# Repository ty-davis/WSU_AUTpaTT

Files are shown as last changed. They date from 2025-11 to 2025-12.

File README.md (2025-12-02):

# WSU_AUTpaTT

This repository contains all the files necessary to
build and operate the WSU_AUTpaTTv3, a device which
is used to characterize antennas in 3D. Lead by students
at Weber State University, WSU_AUTpaTTv3 is a project
which promotes collaboration and helps students learning
about electromagnetic radiation.

## Usage

The documentation is provided in the `docs/WSU_AUTpaTTv3_docs.pdf`
and outlines the contruction and operation of the device.

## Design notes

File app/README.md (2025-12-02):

# WSU_AUTpaTT
SDR-based antenna pattern measurement python code

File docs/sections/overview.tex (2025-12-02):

\chapter{Overview}

AUTpaTT v3 (Antenna Under Test Pattern Tracking, Version 3) is a low-cost, open-source 3-axis antenna pattern measurement system designed for education, research, and outreach.

This document is intended for a new user who receives the project files (for example via GitHub), purchases the required hardware, assembles the mechanical and electrical system, loads the firmware, runs the GUI, and successfully performs antenna measurements.

\section{System Goals}

\begin{itemize}
  \item Provide a low-cost, open-source antenna pattern measurement system.
  \item Use commercial off-the-shelf (COTS) and 3D-printed components where possible.
  \item Support three-axis motion (Azimuth, Elevation, Mast/Rotation).
  \item Integrate with software-defined radios (SDRs) for flexible RF measurements.
  \item Offer an easy-to-use GUI for control, data collection, and visualization.
\end{itemize}

\section{Assumed Background}

This guide assumes the user has basic familiarity with:

\begin{itemize}
  \item Microcontrollers and serial communication.
  \item 3D printing and/or mechanical assembly.
  \item Python environments and package installation.
\end{itemize}

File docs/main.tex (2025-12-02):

\documentclass[11pt,a4paper]{report}

\usepackage[margin=1in]{geometry}
\usepackage[T1]{fontenc}
\usepackage[utf8]{inputenc}
\usepackage{lmodern}
\usepackage{graphicx}
\usepackage{hyperref}
\usepackage{float}
\usepackage{booktabs}
\usepackage{siunitx}
\usepackage{listings}
\usepackage{xcolor}
\usepackage{svg}

\lstdefinestyle{mystyle}{
    backgroundcolor=\color{gray!5},   
    commentstyle=\color{green!60!black},
    keywordstyle=\color{blue},
    numberstyle=\tiny\color{gray},
    stringstyle=\color{orange},
    basicstyle=\ttfamily\small,
    breakatwhitespace=false,         
    breaklines=true,                 
    captionpos=b,                    
    keepspaces=true,                 
    % numbers=left,                    
    numbersep=5pt,                  
    showspaces=false,                
    showstringspaces=false,
    showtabs=false,                  
    tabsize=4,
    frame=single,
    rulecolor=\color{black!30},
    xleftmargin=10pt,
    framexleftmargin=10pt,
    framexrightmargin=5pt,
    framexbottommargin=5pt
}

\lstset{style=mystyle}

\hypersetup{
  colorlinks=true,
  linkcolor=blue,
  urlcolor=blue,
  citecolor=blue
}

\setlength{\parindent}{0pt}

\title{AUTpaTT v3\\\large Open-Source Antenna Pattern Measurement System\\Build and User Documentation}
\author{Weber State University\\Senior Capstone Project}
\date{\today}

\begin{document}

\maketitle
\tableofcontents
\clearpage

\include{sections/overview}               % 1
\include{sections/project_structure}      % 2
\include{sections/bom}                    % 3
\include{sections/mechanical_assembly}    % 4
\include{sections/electronics_wiring}     % 5
\include{sections/firmware}               % 6
\include{sections/gui}                    % 7
\include{sections/params}                 % 8
\include{sections/measurement_procedure}  % 9
\include{sections/troubleshooting}        % 10
\include{sections/acknowledgments}        % 11

\end{document}

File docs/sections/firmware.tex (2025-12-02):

\chapter{Firmware (STM32)}

\section{Firmware Contents}

The \texttt{/firmware/} directory should contain:

\begin{itemize}
  \item STM32CubeMX project configuration (if used).
  \item C source code and header files.
  \item A precompiled \texttt{.hex} or \texttt{.bin} file for quick flashing.
\end{itemize}

\section{Toolchain}

\begin{itemize}
  \item \textbf{STM32CubeProgrammer} for flashing firmware.
  \item Optional: \textbf{STM32CubeIDE} or other GCC-based toolchain for development.
\end{itemize}

\section{Flashing Procedure}

\begin{enumerate}
  \item Connect the STM32 Nucleo-L010RB board to the computer via USB.
  \item Open STM32CubeProgrammer and select the ST-LINK connection.
  \item Load the provided \texttt{.hex} file.
  \item Erase and program the device.
  \item Reset the board and verify that it enumerates as a serial port.
\end{enumerate}

\section{Serial Protocol} \label{sec:serial_protocol}

Describe here the basic serial commands used between the GUI and the firmware, for example:

\begin{itemize}
  \item Command to move to a given Azimuth/Elevation angle.
  \item Command to home each axis.
  \item Command to query current motor positions.
\end{itemize}

This documentation allows others to re-implement the controller if desired.

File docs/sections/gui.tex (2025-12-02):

\chapter{GUI Installation and Usage}

\section{Environment Setup}

The GUI is implemented in Python using PyQt6. A basic environment setup might be:

\begin{lstlisting}[language=bash]
python -m venv venv
source venv/bin/activate   # Windows: venv\Scripts\activate
pip install pyqt6 pyqt6-tools numpy matplotlib pyserial
# Add SDR-related packages as needed
\end{lstlisting}

\section{Launching the GUI}

From the \texttt{/gui/} directory:

\begin{lstlisting}[language=bash]
python main.py
\end{lstlisting}

\section{Main Features}

\begin{itemize}
  \item Connect/disconnect from the STM32 controller via serial port.
  \item Manual control of azimuth, and elevation.
  \item Display of current motor positions.
  \item Configuration of sweep ranges and resolution.
  \item Starting and stopping automated measurement runs.
  \item Visualization of 2D or 3D radiation patterns.
\end{itemize}

Include screenshots or GUI layout diagrams in the \texttt{/docs/} folder and reference them here.

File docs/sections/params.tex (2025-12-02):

\chapter{Configuration: \texttt{params.json}}

The file \texttt{params.json} contains configuration parameters used by both the firmware and GUI. Typical fields include:

\begin{itemize}
  \item Motor steps per revolution.
  \item Gear ratios for each axis.
  \item Default sweep ranges and step sizes.
  \item SDR sample rates and gains.
  \item Serial port settings (baud rate, timeouts, etc.).
\end{itemize}

\section{Editing Parameters}

Parameters may be edited in several ways:

\begin{itemize}
  \item Directly in a text editor (keeping valid JSON syntax).
  \item Through GUI controls that read and write this file.
\end{itemize}

Document here any parameters that are especially important for calibration and system performance.

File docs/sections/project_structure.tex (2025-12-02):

\chapter{Project Structure from GitHub}

After cloning the AUTpaTT v3 repository from GitHub, the expected directory structure is:

\begin{itemize}
  \item \textbf{/firmware/} -- STM32 Nucleo-L010RB source code, configuration files, and precompiled binaries.
  \item \textbf{/app/} -- Python app (using PyQt6) graphical user interface for system control and visualization.
  \item \textbf{/mechanical/} -- 3D models (STL, CAD), mechanical drawings, and assembly diagrams.
  \item \textbf{/electronics/} -- Schematics, wiring diagrams, and optional PCB design files.
  \item \textbf{/docs/} -- Additional documentation, figures, and exported PDFs.
  \item \textbf{/config/} or root file \texttt{params.json} -- System configuration parameters.
\end{itemize}

Each folder should include a minimal \texttt{README} that describes its content and how it is used.

You can add or update this structure as the project evolves.

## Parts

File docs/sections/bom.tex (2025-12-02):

\chapter{Bill of Materials (BOM)}

This chapter lists the components required to build AUTpaTT v3. Part numbers and vendors are examples; replace them with the exact parts you select.

\section{COTS items}

\begin{table}[H]
  \centering
  \makebox[\textwidth][c]{
      \begin{tabular}{@{}lll l@{}}
        \toprule
        Qty & Item & Part Number & Notes \\
        \midrule
        1 & STM32 Nucleo-L010RB dev board & NUCLEO-L010RB & Main controller \\
        2 & Stepper motor driver & TB6600 & One per axis \\
        1 & Power supply, 12~V & -- & \SIrange{3}{5}{A} recommended \\
        1 & USB-A to Mini-USB-B cable & -- & Recommend buying a 10ft cord \\
        -- & Assorted jumper wires & -- & Female--female and male--female \\
        2 & Stepper motor & NEMA17 & Azimuth, Elevation \\
        1 & Transmit Antenna & -- & Parabolic WIFI \\
        1 & Receive Antenna & -- & This is the AUT\\
        1 & Plastic Ball Bearing & McMaster-Carr, 6455K147 & --  \\
        1 & Plastic Ball Bearing & McMaster-Carr, 6455K54 & --\\
        1 & SMA Rotary Joint & FMRJ1002 & --\\
        2 & Timing Belt Pully & GT2-516-6mm & --\\
        1 & Timing Belt Pully & GT2-560-6mm & --\\
        2 & Hack RF Radios & -- & --\\
        - & SMA Cables & -- & Female to Female\\
        \bottomrule
      \end{tabular}
  }
  \caption{Core electronics components.}
\end{table}

\section{3D Printed Parts}

\begin{table}[H]
  \centering
  \begin{tabular}{@{}lll l@{}}
    \toprule
    Qty & Item & Example & Notes \\
    \midrule
    1 & v3\_mastYokeArmLeft & -- & --\\
    1 & v3\_mastYokeArmRight & -- & --\\
    1 & v3\_mastYokeBase & -- & --\\
    1 & v3\_mastYokeMotorMount & -- & --\\
    1 & v3\_AUT\_mountingPlate & -- & --\\
    1 & v3\_tube & -- & Can be made from plastic tube\\
    1 & v2\_mastBaseGear & -- & --\\
    1 & v2\_baseBearingFixture & -- & --\\
    1 & v2\_nemaMotorMount & -- & --\\
    \bottomrule
  \end{tabular}
  \caption{Printed Compoenents.}
\end{table}

\section{Mechanical Structure}

\begin{itemize}
  \item 3D-printed parts: all STL files in \texttt{/mechanical/} folder.
  \item Mechanical Assembly described in assembly drawing.
\end{itemize}

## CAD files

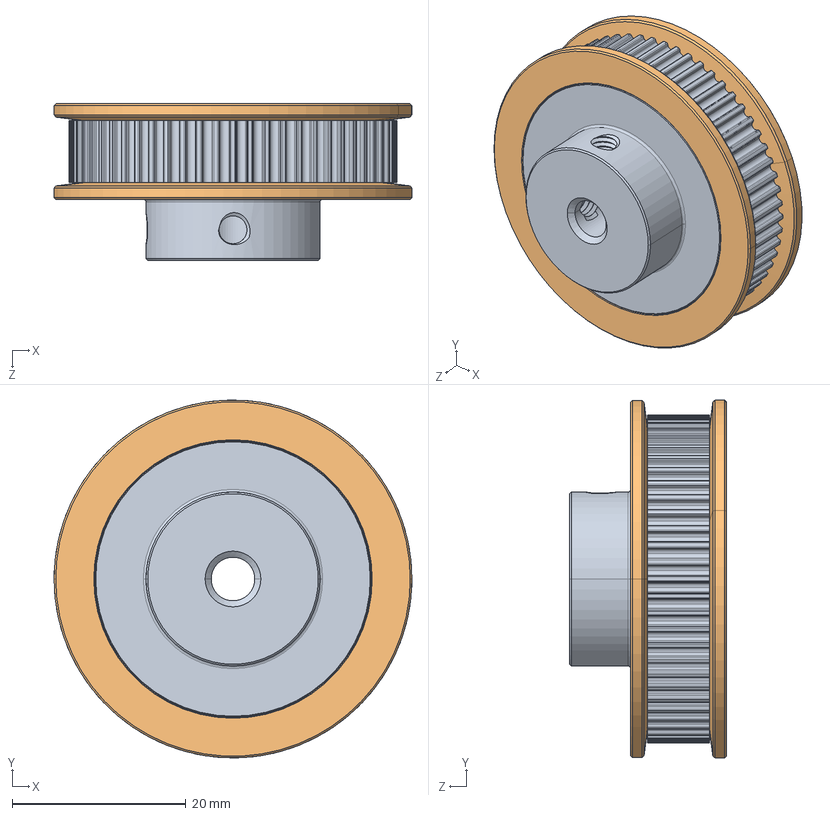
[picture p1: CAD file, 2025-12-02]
mechanical/solid models/60pitch pulley GT2 6mm ASSEMBLY.STEP
41.1 x 41.1 x 18.0 mm
Pulley part01 GT2 6mm
Gear 60pitch part02 x 2

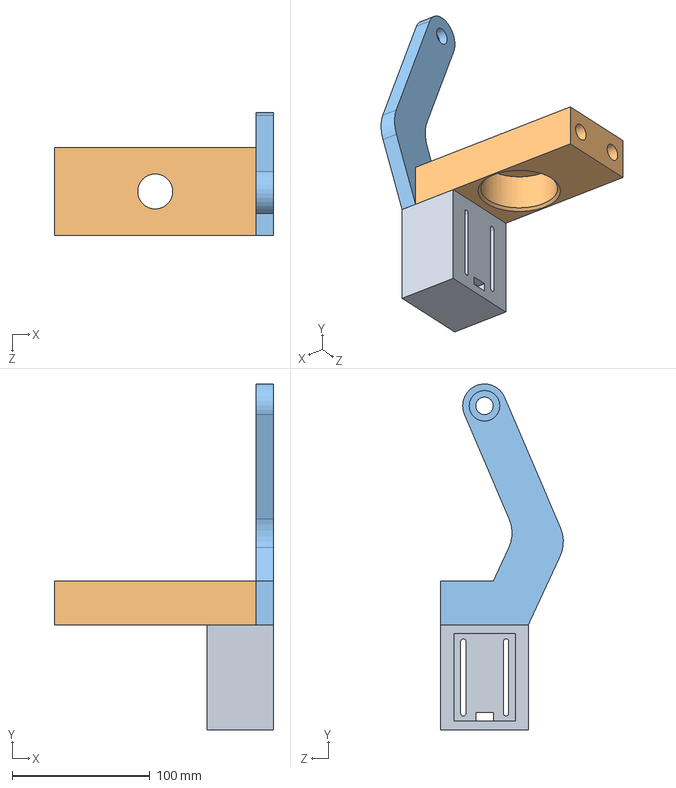
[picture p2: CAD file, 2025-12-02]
mechanical/solid models/v3_mastYoke.SLDASM
158.8 x 250.8 x 88.8 mm
v3_mastYokeArmLeft
v3_mastYokeBase
v3_mastYokeMotorMount

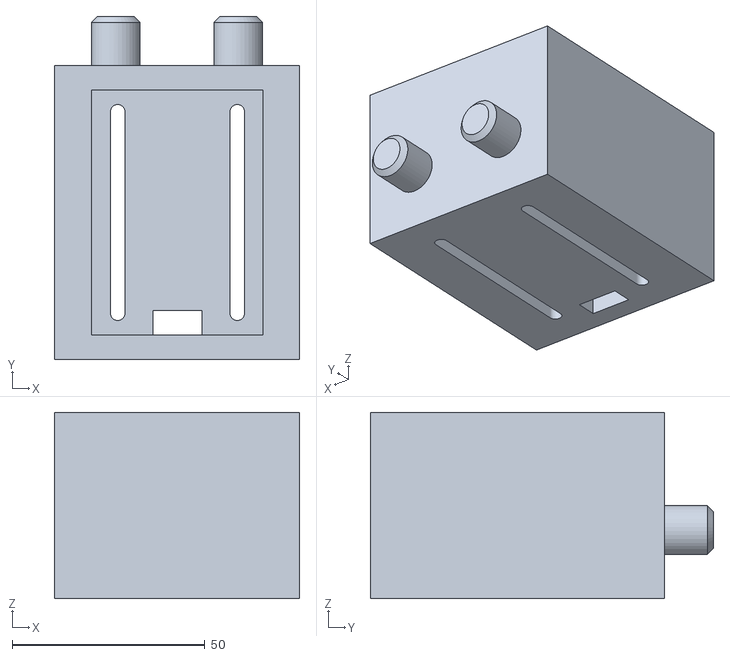
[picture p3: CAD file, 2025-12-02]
mechanical/stl exports (use me in slicer ide)/antenna support_v3_motor_mount.STL
63.5 x 88.9 x 48.3

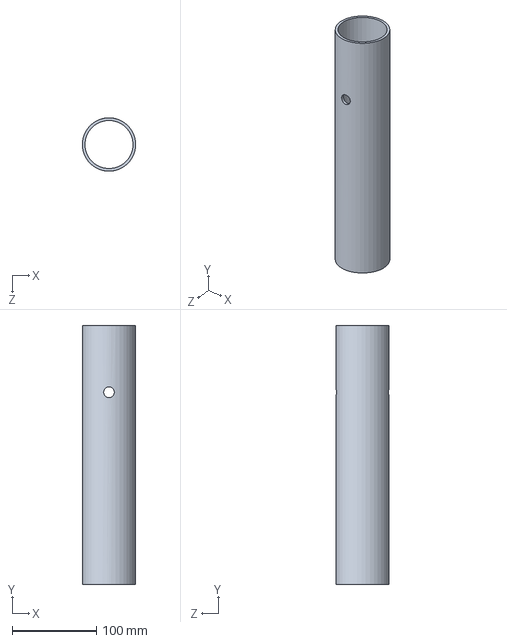
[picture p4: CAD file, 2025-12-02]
mechanical/solid models/v3_tube.SLDPRT
63.4 x 308.0 x 63.5 mm

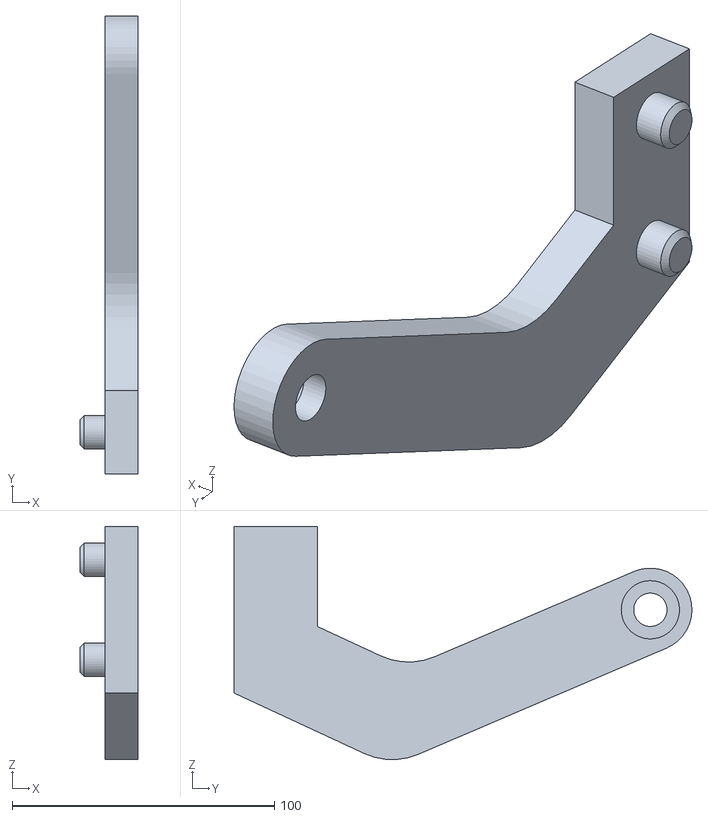
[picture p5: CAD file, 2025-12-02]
mechanical/stl exports (use me in slicer ide)/antenna support_v3_arm2.STL
22.2 x 174.6 x 88.8

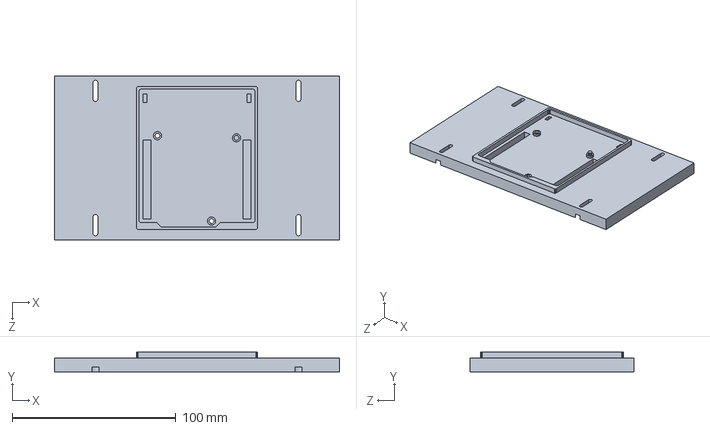
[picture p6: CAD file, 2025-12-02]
mechanical/solid models/STM_mount_plate.SLDPRT
174.0 x 12.0 x 100.0 mm

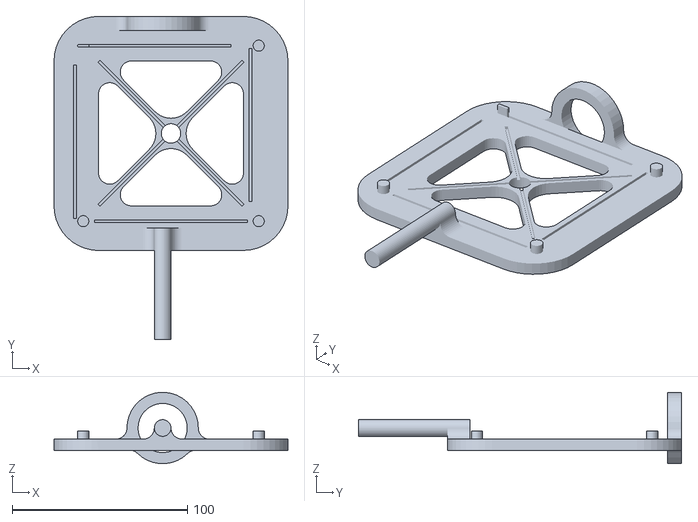
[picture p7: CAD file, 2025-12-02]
mechanical/stl exports (use me in slicer ide)/antenna mount_v3.STL
133.4 x 184.1 x 40.6

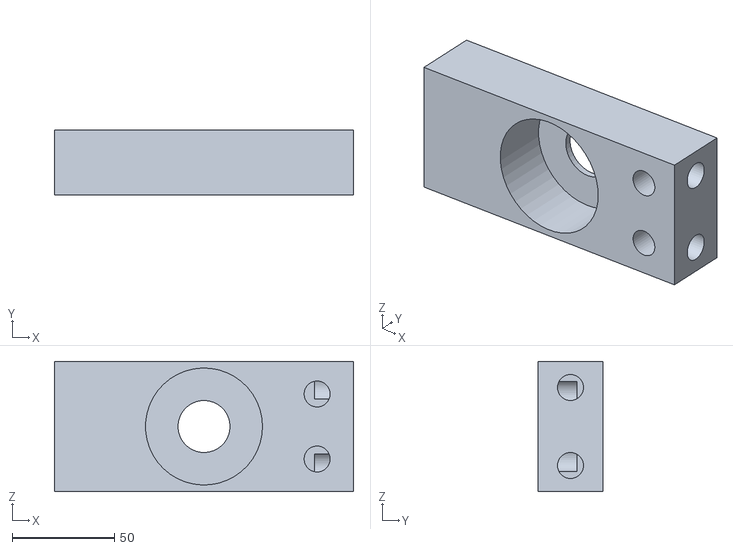
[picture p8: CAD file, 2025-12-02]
mechanical/stl exports (use me in slicer ide)/antenna support_v3_antenna base.STL
146.1 x 31.7 x 63.5

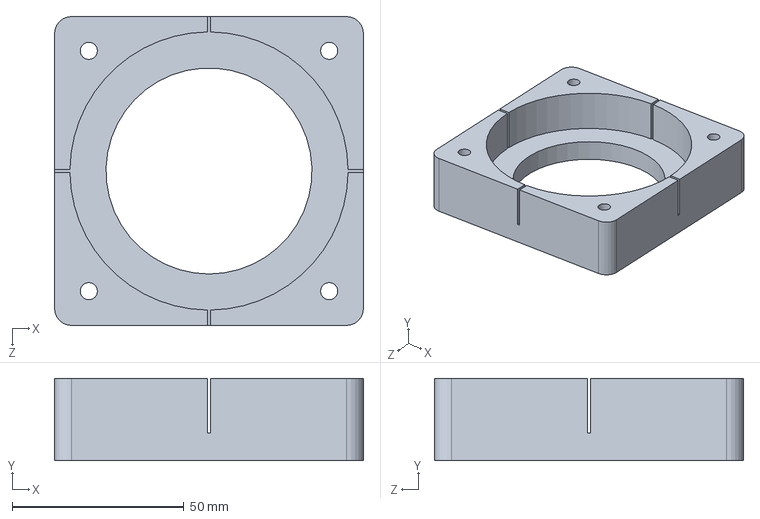
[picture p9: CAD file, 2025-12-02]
mechanical/solid models/v2_Base_BearingFixture.SLDPRT
90.0 x 24.0 x 90.0 mm

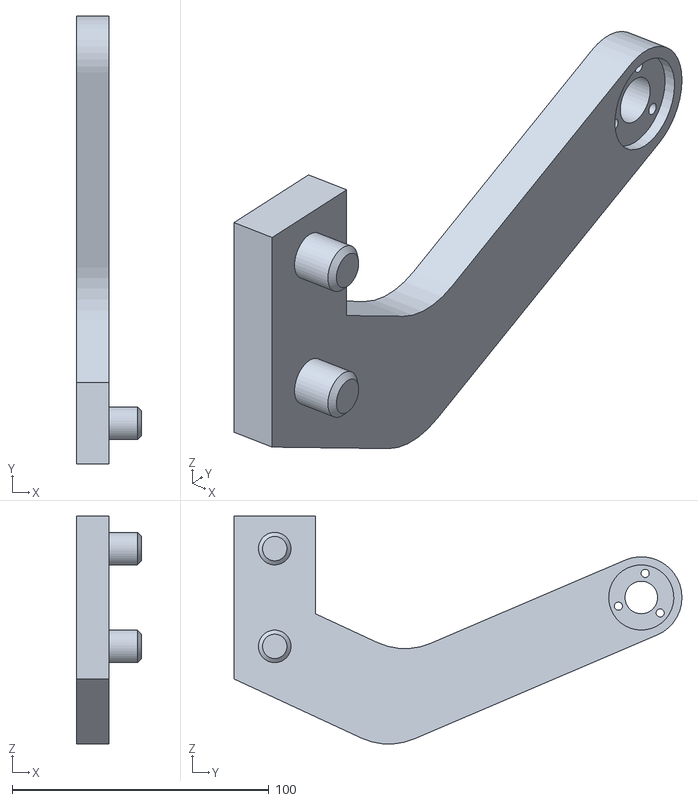
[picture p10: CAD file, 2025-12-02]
mechanical/stl exports (use me in slicer ide)/antenna support_v3_arm1.STL
25.4 x 174.6 x 88.8

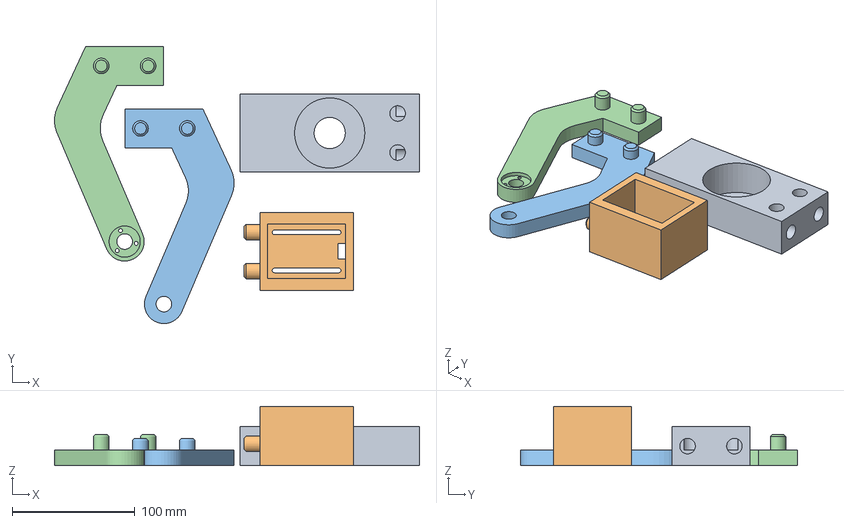
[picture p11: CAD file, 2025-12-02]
mechanical/stl exports (use me in slicer ide)/antenna support.3mf
296.9 x 225.5 x 48.3 mm
antenna support_v3_antenna base.STL
antenna support_v3_motor_mount.STL
antenna support_v3_arm2.STL
antenna support_v3_arm1.STL

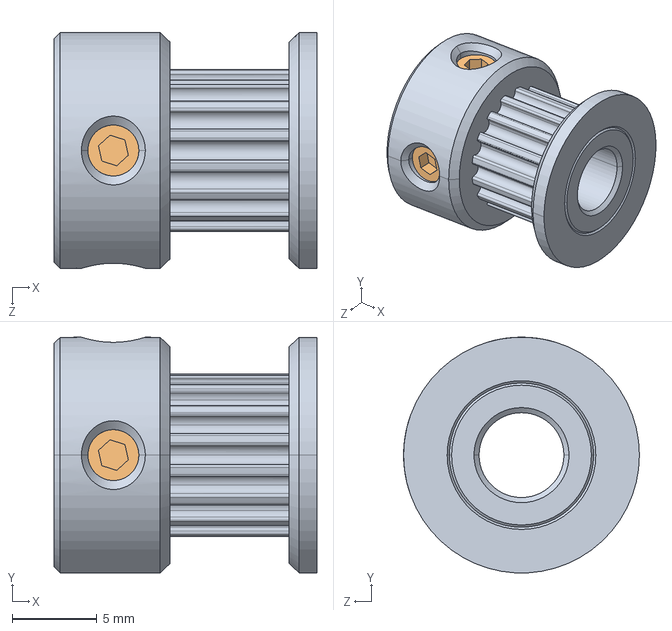
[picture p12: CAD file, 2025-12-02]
mechanical/solid models/GT2_16T.STEP
15.5 x 13.9 x 13.9 mm

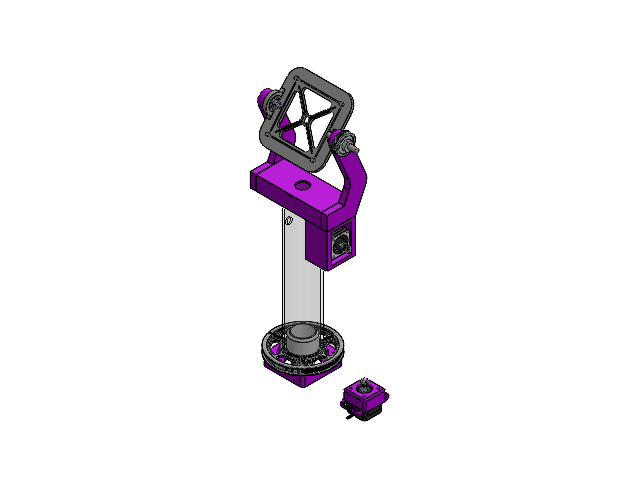
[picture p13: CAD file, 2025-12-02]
mechanical/solid models/v3AUTpaTT.SLDASM
v3_mastYokeArmLeft
v3_mastYokeArmRight
v3_mastYokeBase
v3_mastYokeMotorMount
v3_AUT_mountingPlate
6455K147_Plastic Ball Bearing
6455K54_Plastic Ball Bearing
FMRJ1002_3D.step
v3_tube
v2MastBase_Gear
v2_Base_BearingFixture
Nema17-17HS16-2004S1.step x 2
v2Nema_MotorMount
GT2_16T.step x 2
Pulley part01 GT2 6mm.STEP
Gear 60pitch part02.STEP x 2

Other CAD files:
mechanical/solid models/v3_mastYokeMotorMount.SLDPRT
mechanical/stl exports (use me in slicer ide)/STM_mount_plate.STL
mechanical/solid models/v3_mastYokeBase.SLDPRT
mechanical/solid models/Nucleo-64_Base.SLDPRT
mechanical/solid models/v3_mastYokeArmLeft.SLDPRT
mechanical/solid models/6455K147_Plastic Ball Bearing.SLDPRT
mechanical/solid models/6455K54_Plastic Ball Bearing.SLDPRT
mechanical/solid models/FMRJ1002_3D.step
mechanical/solid models/GT2_16T.SLDPRT
mechanical/solid models/Nema17-17HS16-2004S1.STEP
mechanical/solid models/v2MastBase_Gear.SLDPRT
mechanical/solid models/v2Nema_MotorMount.SLDPRT
mechanical/solid models/v3AUTpaTT.SLDDRW
mechanical/solid models/v3_AUT_mountingPlate.SLDPRT
mechanical/solid models/v3_mastYokeArmRight.SLDPRT

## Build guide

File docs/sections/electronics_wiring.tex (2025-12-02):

\chapter{Electronics and Wiring}

\section{Overview}

The electronics subsystem includes the STM32 Nucleo-L010RB board, stepper motor drivers, stepper motors, power supply, and connections to the SDRs and host computer.

\section{Wiring Guidelines}

Use the wiring diagram shown in Fig. \ref{fig:wiring} to connect the components of the system.
The pins on the STM32 are shown with two labels denoting the pin numbers of the STM32, and the pins
of the corresponding Arduino header that match and are shown on the board.

\begin{figure}[h!]
    \footnotesize
    \begin{centering}
    \includesvg[width=\textwidth]{figs/wiring}
    \end{centering}
    \caption{Wiring Diagram for STM32 and Motor Drivers.}
    \label{fig:wiring}
\end{figure}

A +12V power supply is required to power the motor drivers and is omitted here for brevity.

\section{Stepper Motor Drivers}

Each stepper driver (TB6600) connects to:
\begin{itemize}
  \item A Stepper Motor
  \item Power: +12~V and GND.
  \item Control signals from STM32: PUL, DIR, and ENABLE.
\end{itemize}

Unless another pulse/revolution ratio is desired and sent to the STM32 via the \hyperref[sec:serial_protocol]{serial protocol},
set the TB6600 motor drivers to 800 pulse/revolution.

\section{STM32 Nucleo Connections}

\begin{itemize}
  \item USB connection to the host computer for programming and serial communication.
  \item GPIO pins connected to each driver's PUL(-), DIR(-), and EN(-) pins.
  \item 5V pin connected to each driver's PUL(+), DIR(+), and EN(+) pins.
\end{itemize}

\section{SDR Connections}

\begin{itemize}
  \item The transmit SDR \& receiver SDR connects to the host computer via USB.
  \item The transmit SDR connects to WIFI band parabolic antenaa.
  \item The receive SDR connects to the AUT.
\end{itemize}

\begin{figure}[h!]
    \footnotesize
    \begin{centering}
    \includesvg[width=\textwidth]{figs/wiring_computer}
    \end{centering}
    \caption{Wiring Diagram for STM32 and Motor Drivers.}
    \label{fig:wiring}
\end{figure}

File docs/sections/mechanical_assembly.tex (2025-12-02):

\chapter{Mechanical Assembly}

This chapter describes the mechanical assembly of AUTpaTT v3. Detailed drawings and 3D models are provided in the \texttt{/mechanical/} directory of the repository.

\section{Printing and Preparing Parts}

\begin{enumerate}
  \item Print all STL files using suitable material (e.g., PLA, ABS, or PETG). The original project was printed using ABS plastic.
  \item Verify interference fit between bearings and housings, verify clearances, clean up any support material or rough edges.
\end{enumerate}

\section{Base Frame and Azimuth Axis}

\begin{enumerate}
  \item Assemble the following to the base plate per the assembly drawing.
    \begin{enumerate}

        \item v2\_nemaMotorMount w/ the azimuth stepper motor installed.
        \item v2\_baseBearingFixture
        \item GT2-516-6mm timing belt pully
    \end{enumerate}
  \item Assemble the mast bearing into the base bearing fixture and the v2\_mastBaseGear into the bearing. Verify interference fits for both items. Tape can be added to the parts to tighten the fit.
  \item Assemble the timing belt to the base gear and timing belt on the stepper motor then tighten the belt by sliding the motor mount in the slots and tighten down the motor mount bolts.
\end{enumerate}

\section{Elevation Axis}

\begin{enumerate}
  \item Mount the SMA Rotary joint to the v3\_mastYokeArmRight using fasteners.
  \item Assemble the larger plastic ball bearing (6455K147) into the v3\_AUT\_mounting plate.
  \item Assemble the other plastic ball bearing (6455K54) into the v3\_mastYokeArmLeft.
  \item Assemble the right and left arm to the mounting plate as shown in the assembly drawing and press the "dowels" on the arms into the v3\_mastYokeBase.
  \item Assemble the elevation stepper motor into the v3\_mastYokeMotorMount as shown in the assembly drawing. Do not fully tighten fasteners yet.
  \item Press the "dowels" of the motor mount into the yoke base with the rotor of the motor facing out per the assembly drawing.
  \item Assemble the GT2-516-6mm timing belt pully to the stepper motor and the GT2-560-6mm timing belt pully to the mounting plate. Note: the center bore of the GT2-560-6mm pully will need to be drilled out per the drawing to assemble correctly. 
  \item Assemble the timing belt to both pullies and tighten by sliding the stepper motor down in the mount and tightening the fasteners. 
  \item Press the tube into the mast yoke and then the tube to the base gear to finalize the mechanical assembly.
\end{enumerate}

\section{Finishing Assembly}

\begin{enumerate}
  \item Assemble the AUT to the mounting plate, a small flexible SMA cable will be needed to be assembled from the AUT to the rotary joint. 
  \item Assemble a longer SMA cable to the other side of the rotary joint and fish it through the side of the tube so it does not get tangled. This cable will go to the "receiving" SDR. 
  \item Assemble the motor drivers and micro controller to the v3\_STM\_mountingPlate.
  \item Wire the stepper motors and the independent power supply to the motor drivers and the motor drivers to the micro-controller per the wiring diagram. 
\end{enumerate}

\section{Mechanical Checks}

\begin{itemize}
  \item Ensure that all axes rotate freely with no binding.
  \item Check that cables and wires can be routed without snagging or wrapping around moving parts.
  \item Tighten all fasteners and recheck alignment.
\end{itemize}

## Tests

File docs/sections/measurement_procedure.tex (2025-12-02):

\chapter{Measurement Procedure}

This chapter describes a typical measurement workflow.

\section{Preparation}

\begin{enumerate}
  \item Verify all mechanical connections and ensure that all axes move freely.
  \item Power on the system and connect the STM32 and SDRs to the host computer.
  \item Launch the GUI and connect to the STM32 serial port.
\end{enumerate}

\section{Homing and Zeroing}

\begin{enumerate}
  \item Home each axis using the GUI (or manually move to a known reference position).
  \item Confirm that position readouts match expected zero positions.
\end{enumerate}

\section{Configuring a Sweep}

\begin{enumerate}
  \item Set the Azimuth start/stop angles and step size.
  \item Set the Elevation range (if used) and step size.
  \item Configure SDR parameters (center frequency, gain, sample rate).
\end{enumerate}

\section{Running a Measurement}

\begin{enumerate}
  \item Start the sweep from the GUI.
  \item Monitor progress and verify that the AUT moves as expected.
  \item Upon completion, save the measured data (e.g., CSV file).
\end{enumerate}

\section{Data Visualization}

\begin{itemize}
  \item Use built-in plotting in the GUI for quick inspection.
  \item Optionally, export data for use in external tools (MATLAB, Python scripts, etc.).
\end{itemize}

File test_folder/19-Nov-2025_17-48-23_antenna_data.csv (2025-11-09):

Experiment
% Mast Angle | Arm Angle | Background RSSI | Transmission RSSI

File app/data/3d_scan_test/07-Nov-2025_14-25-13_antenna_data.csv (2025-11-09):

Experiment
% Mast Angle | Arm Angle | Background RSSI | Transmission RSSI
-180 | -90 | 0.0 | 0.00411684038649162
-179 | -90 | 0.0 | 0.004273664321098818
-178 | -90 | 0.0 | 0.0044003070100847785
-177 | -90 | 0.0 | 0.00453865860839762
-176 | -90 | 0.0 | 0.004700895935805575
-175 | -90 | 0.0 | 0.004802841253129567
-174 | -90 | 0.0 | 0.004979065484833295
-173 | -90 | 0.0 | 0.005076450692446571
-172 | -90 | 0.0 | 0.005093597296887831
-171 | -90 | 0.0 | 0.00520148505978169
-170 | -90 | 0.0 | 0.005229538670096327
-169 | -90 | 0.0 | 0.005235615744217269
-168 | -90 | 0.0 | 0.005238796664103269
-167 | -90 | 0.0 | 0.00529496181347633
-166 | -90 | 0.0 | 0.005263079576342285
-165 | -90 | 0.0 | 0.0052378404977674676
-164 | -90 | 0.0 | 0.00522949492760347
-163 | -90 | 0.0 | 0.005087614010076423
-162 | -90 | 0.0 | 0.004946570425727888
-161 | -90 | 0.0 | 0.004802225764118687
-160 | -90 | 0.0 | 0.004718129664752715
-159 | -90 | 0.0 | 0.00448882863260915
-158 | -90 | 0.0 | 0.004361233526742504
-157 | -90 | 0.0 | 0.004182684319354149
-156 | -90 | 0.0 | 0.0040548761443367975
-155 | -90 | 0.0 | 0.0038261078965352944
-154 | -90 | 0.0 | 0.003637641713021363
-153 | -90 | 0.0 | 0.0034640284156706278
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

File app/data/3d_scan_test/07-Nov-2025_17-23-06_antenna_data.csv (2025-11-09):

Experiment
% Mast Angle | Arm Angle | Background RSSI | Transmission RSSI
-180 | -90 | 0.0 | 0.0035297520595307056
-179 | -90 | 0.0 | 0.003655941559245732
-178 | -90 | 0.0 | 0.0037861012826280486
-177 | -90 | 0.0 | 0.0038954217152386617
-176 | -90 | 0.0 | 0.0040336727183365485
-175 | -90 | 0.0 | 0.0041476016041917625
-174 | -90 | 0.0 | 0.004244900141386852
-173 | -90 | 0.0 | 0.00436989471997877
-172 | -90 | 0.0 | 0.004471388982411234
-171 | -90 | 0.0 | 0.004539627817103733
-170 | -90 | 0.0 | 0.0046478961513783095
-169 | -90 | 0.0 | 0.00468491141394872
-168 | -90 | 0.0 | 0.004732468586729701
-167 | -90 | 0.0 | 0.0047327627429095374
-166 | -90 | 0.0 | 0.004787630462647476
-165 | -90 | 0.0 | 0.004735022993450363
-164 | -90 | 0.0 | 0.004714587640699876
-163 | -90 | 0.0 | 0.004730252232252236
-162 | -90 | 0.0 | 0.004592589571733637
-161 | -90 | 0.0 | 0.004513919607516239
-160 | -90 | 0.0 | 0.004404593871840091
-159 | -90 | 0.0 | 0.0042957471446504894
-158 | -90 | 0.0 | 0.004204804774847104
-157 | -90 | 0.0 | 0.004077711335980914
-156 | -90 | 0.0 | 0.003960402165598614
-155 | -90 | 0.0 | 0.003793658109248999
-154 | -90 | 0.0 | 0.0036031659423111876
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

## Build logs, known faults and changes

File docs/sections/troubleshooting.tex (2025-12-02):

\chapter{Troubleshooting}

\section{Common Issues}

\subsection{Board Not Detected / USB Problems}

\begin{itemize}
  \item Check the USB cable; use a known good USB-A to Mini-USB-B cable.
  \item Some issues (e.g., ``USB LSD'' blinking) may indicate insufficient power or communication errors.
  \item Try a different USB port or powered hub.
\end{itemize}

\subsection{Stepper Motors Not Moving or Stalling}

\begin{itemize}
  \item Verify wiring from drivers to motors and from drivers to STM32.
  \item Check that the driver is receiving 12~V power.
  \item Adjust the current limit on the driver; too low can cause missed steps, too high can overheat.
\end{itemize}

\subsection{No SDR Signal}

\begin{itemize}
  \item Confirm that the correct SDR device index is selected in the GUI.
  \item Check frequency, gain, and antenna connections.
  \item Test the SDR separately with a simple spectrum viewer application.
\end{itemize}

\section{Debugging Tips}

\begin{itemize}
  \item Use serial terminal software to send simple commands to the STM32 and observe responses.
  \item Enable debug prints in the firmware and/or GUI.
  \item Test one axis at a time before running full 3D sweeps.
\end{itemize}

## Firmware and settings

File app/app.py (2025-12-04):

import sys
from PyQt6 import QtWidgets, uic
from PyQt6.QtGui import QShortcut, QKeySequence
from PyQt6.QtCore import QTimer
import plotting
import matplotlib.pyplot as plt
from params_manager import ParamsManager
import pprint
import time
import os
from motor_connection import MotorConnection
from serial.serialutil import SerialException
from scans import all_scans, AbstractScan
from datetime import datetime
import asyncio
import qasync


class MyMainWindow(QtWidgets.QMainWindow):
    def __init__(self, *args, **kwargs):
        super().__init__(*args, **kwargs)
        uic.loadUi("./gui/window.ui", self)

        self.setWindowTitle("WSU AUTpaTTv3")

        # Create timer
        self.timer = QTimer()
        self.timer.timeout.connect(self.poll_state)
        self.timer.start(100)   # update every 150 ms

        # load the parameters
        self.params_man = ParamsManager()

        self.mast_steps.setText(str(self.params_man.params['mast_steps']))
        self.mast_steps.editingFinished.connect(self.update_params)

        self.arm_steps.setText(str(self.params_man.params['arm_steps']))
        self.arm_steps.editingFinished.connect(self.update_params)

        self.logfile = None

        # configure the motor connection
        self.motor_conn = None
        # self.connect_to_stm32()
        self.update_motor_connection_state()

        # self.timer = QTimer()
        # self.timer.timeout.connect(self.poll_position)
        # self.timer.start(1000)

        # actions
        self.actionOpen_scan.triggered.connect(self.open_scan_file)
        self.actionMove_with_Arrow_Keys.triggered.connect(self.move_with_arrow_keys)
        self.actionEdit_Parameters.triggered.connect(self.edit_parameters)
        self.actionView_Parameters.triggered.connect(self.view_parameters)
        self.actionLoad_Parameters.triggered.connect(self.load_parameters)

        # buttons
        self.clear_plot_b.clicked.connect(self.clear_plot)
        self.move_with_arrows_button.clicked.connect(self.actionMove_with_Arrow_Keys.trigger)
        self.view_params_b.clicked.connect(self.actionView_Parameters.trigger)
        self.load_params_b.clicked.connect(self.load_parameters)

        self.start_button.clicked.connect(self.run_test)
        self.cancel_button.clicked.connect(self.cancel_test)
        self.moveAzimuthByButton.clicked.connect(lambda: self.motor_command('azm'))
        self.moveElevationByButton.clicked.connect(lambda: self.motor_command('elv'))
        self.moveAzimuthToButton.clicked.connect(lambda: self.motor_command('azm_to'))
        self.moveElevationToButton.clicked.connect(lambda: self.motor_command('elv_to'))
        self.calibrateButton.clicked.connect(lambda: self.motor_command('calibrate'))
        self.lockUnlockButton.clicked.connect(lambda: self.motor_command('toggle_lock'))

        self.connect_to_stm32_button.clicked.connect(self.connect_to_stm32)
        self.disconnect_from_stm32_button.clicked.connect(self.disconnect_from_stm32)

        self.cancel_button.hide()

        for scan in all_scans:
            self.select_scan.addItem(scan.name, scan)

    def update_params(self):
        try:
            self.params_man.params["mast_steps"] = int(self.mast_steps.text())
        except ValueError:
            self.mast_steps.setText(str(self.params_man.params["mast_steps"]))

        try:
            self.params_man.params["arm_steps"] = int(self.arm_steps.text())
        except ValueError:
            self.arm_steps.setText(str(self.params_man.params["arm_steps"]))

    @qasync.asyncSlot()
    async def poll_state(self):
        if not self.motor_conn or not self.motor_conn.serial_connection:
            return
        result = await self.motor_conn.send_command_async("GET_STATE")
        azm = int(result['azm']) / 8
        azm_degrees = azm * 10000 / self.params_man.params['azm_pulse_rev'] * 360 / self.params_man.params['azm_tooth_ratio']
        elv = int(result['elv']) / 8
        elv_degrees = elv * 10000 / self.params_man.params['elv_pulse_rev'] * 360 / self.params_man.params['elv_tooth_ratio']
        locked = bool(result['locked'])
        self.azimuthLocation.display(round(azm_degrees))
        self.elevationLocation.display(round(elv_degrees))
        if locked:
            self.lockUnlockButton.setText('Unlock Motors')
        else:
            self.lockUnlockButton.setText('Lock Motors')
        self.start_button.setEnabled(locked)
        self.moveAzimuthByButton.setEnabled(locked)
        self.moveElevationByButton.setEnabled(locked)
        self.moveAzimuthToButton.setEnabled(locked)
        self.moveElevationToButton.setEnabled(locked)
        self.calibrateButton.setEnabled(locked)
        self.move_with_arrows_button.setEnabled(locked)

    def edit_parameters(self):
        ...

    @qasync.asyncSlot()
    async def motor_command(self, dir):
        if self.motor_conn and self.motor_conn.serial_connection:
            try:
                if dir == 'azm':
                    if self.moveAzimuthByValue.text():
                        amount = int(self.moveAzimuthByValue.text())
                        await self.motor_conn.send_command_async("ma", amount)
                elif dir == 'elv':
                    if self.moveElevationByValue.text():
                        amount = int(self.moveElevationByValue.text())
                        await self.motor_conn.send_command_async("me", amount)
                elif dir == 'azm_to':
                    if self.moveAzimuthToValue.text():
                        amount = int(self.moveAzimuthToValue.text())
                        await self.motor_conn.send_command_async("mat", amount)
                elif dir == 'elv_to':
                    if self.moveElevationToValue.text():
                        amount = int(self.moveElevationToValue.text())
                        await self.motor_conn.send_command_async("met", amount)
                elif dir == 'calibrate':
                    await self.motor_conn.send_command_async("c")
                elif dir == 'toggle_lock':
                    await self.motor_conn.send_command_async("tl")
            except SerialException as e:
                self.log(f"Motor communication error: {e}")
                self.update_motor_connection_state()
        else:
            print("error connecting to motors")

    def update_motor_connection_state(self):
        is_connected = bool(self.motor_conn is not None and self.motor_conn.serial_connection)

        # enable/disable buttons according to the connection state
        self.start_button.setEnabled(is_connected)
        self.moveAzimuthByButton.setEnabled(is_connected)
        self.moveElevationByButton.setEnabled(is_connected)
        self.moveAzimuthToButton.setEnabled(is_connected)
        self.moveElevationToButton.setEnabled(is_connected)
        self.calibrateButton.setEnabled(is_connected)
        self.lockUnlockButton.setEnabled(is_connected)
        self.move_with_arrows_button.setEnabled(is_connected)
        if is_connected:
            self.connect_to_stm32_button.hide()
            self.disconnect_from_stm32_button.show()
        else:
            self.connect_to_stm32_button.show()
            self.disconnect_from_stm32_button.hide()

    def log(self, *args):
        self.status_label.setText(' '.join([str(arg) for arg in args]))
        print(datetime.now(), *args)

    @qasync.asyncSlot()
    async def run_test(self):
        scan: AbstractScan = self.select_scan.currentData()
        scan.reset_cancel()
        self.progress_bar.setValue(0)

        scan.populate_state(self.motor_conn,
                            self.params_man.params,
                            self.log,
                            self.progress_bar)
        self.open_datafile()

        results = None
        try:
            self.start_button.hide()
            self.cancel_button.show()
            self.log("Starting scan...")

            results = await scan.run_procedure()
            # toggle start/cancel button and disable a bunch of stuff

            if self.datafile:
                self.log(f"Writing test results to file: {self.datafile.name}")
                plotting.write_csv_file(self.datafile, results)
            else:
                self.log(f"NO DATAFILE TO WRITE TO")
            self.plot_data(results)
        except asyncio.CancelledError:
            self.log("Scan cancelled by user")
        except RuntimeError as e:
            self.log("Error:", e)
        finally:
            self.cancel_button.hide()
            self.start_button.show()
            self.close_datafile()

        return results

    def cancel_test(self):
        scan = self.select_scan.currentData()
        scan.cancel()

        self.cancel_button.hide()
        self.start_button.show()

    @qasync.asyncSlot()
    async def connect_to_stm32(self):
        self.motor_conn = MotorConnection(
            port=self.params_man.params['usb_port'],
            baudrate=self.params_man.params['baudrate'],
            use_scalars=self.params_man.params['stm32_use_scalars'],
            debug=self.params_man.params['debug_stm32'],
        )
        try:
            await self.motor_conn.connect_async()
            self.update_motor_connection_state()
        except SerialException as e:
            print(f"Error connecting to stm32: {e}")

    @qasync.asyncSlot()
    async def disconnect_from_stm32(self):
        if self.motor_conn and self.motor_conn.serial_connection:
            await self.motor_conn.disconnect_async()
        if self.motor_conn:
            self.motor_conn = None
        self.update_motor_connection_state()

    def load_parameters(self):
        file_path, _ = QtWidgets.QFileDialog.getOpenFileName(
            self,
            "Open File",
            "",
            "All Files (*);;Text Files (*.txt);;CSV Files (*.csv)"
        )
        if file_path:
            self.params_man.load_params(file_path)

    def view_parameters(self):
        dialog = ViewParamsDialog(self, self.params_man.params)
        result = dialog.exec()

    def move_with_arrow_keys(self):
        dialog = ArrowsDialog(self, self.motor_conn)
        result = dialog.exec()

    def plot_data(self, data):
        if plotting.is_data_3d(data):
            x, y, z, tri = plotting.process_data_3d(data)

            self.tabWidget.setCurrentIndex(0)
            self.clear_plot()
            self.plot_3d.axes.plot_trisurf(x, y, z, triangles=tri.triangles, cmap=plt.cm.CMRmap, linewidths=0.5, antialiased=True)
            self.plot_3d.canvas.draw()
        else:
            angles, r = plotting.process_data_2d(data)

            self.tabWidget.setCurrentIndex(1)
            self.clear_plot()
            self.plot_2d.axes.plot(angles, r)
            self.plot_2d.canvas.draw()

    def clear_plot(self):
        if self.tabWidget.currentIndex() == 0:
            self.plot_3d.axes.clear()
            self.plot_3d.canvas.draw()
        else:
            self.plot_2d.axes.clear()
            if hasattr(self.plot_2d.axes, 'set_theta_zero_location'):
                self.plot_2d.axes.set_theta_zero_location('N')
                self.plot_2d.axes.set_theta_direction(-1) # clockwise
            self.plot_2d.canvas.draw()

    def open_scan_file(self):
        file_path, _ = QtWidgets.QFileDialog.getOpenFileName(
            self,
            "Open File",
            "",
            "All Files (*);;Text Files (*.txt);;CSV Files (*.csv)"
        )

        if file_path:
            print(f"Opening file now: {file_path}")
            data = plotting.read_csv_file(file_path)
            self.plot_data(data)

    def open_datafile(self):
        filename = time.strftime("%d-%b-%Y_%H-%M-%S") + self.params_man.params["filename"]
        output_file = os.path.join(self.params_man.params['output_folder'], filename)
        os.makedirs(os.path.dirname(output_file), exist_ok=True)

        datafile_fp = open(output_file, 'w')
        datafile_fp.write(self.params_man.params["notes"]+"\n")
        datafile_fp.write("% Mast Angle, Arm Angle, Background RSSI, Transmission RSSI\n")
        self.datafile = datafile_fp
        self.filePathLabel.setText(self.datafile.name)
        return datafile_fp

    def close_datafile(self):
        self.datafile.flush()
        self.datafile.close()
        self.datafile = None


class ArrowsDialog(QtWidgets.QDialog):
    def __init__(self, parent, motor_conn: MotorConnection, *args, **kwargs):
        super().__init__(parent, *args, **kwargs)
        uic.loadUi("./gui/arrows_dialog.ui", self)
        self.motor_conn = motor_conn

        if not motor_conn.serial_connection:
            try:
                motor_conn.connect()
            except Exception as e:
                self.label.setText(f"A connection to the STM32 could not be made: {e}")
                return

        up_shortcut = QShortcut(QKeySequence('Up'), self)
        left_shortcut = QShortcut(QKeySequence('Left'), self)
        down_shortcut = QShortcut(QKeySequence('Down'), self)
        right_shortcut = QShortcut(QKeySequence('Right'), self)

        shift_up_shortcut = QShortcut(QKeySequence('Shift+Up'), self)
        shift_left_shortcut = QShortcut(QKeySequence('Shift+Left'), self)
        shift_down_shortcut = QShortcut(QKeySequence('Shift+Down'), self)
        shift_right_shortcut = QShortcut(QKeySequence('Shift+Right'), self)

        up_shortcut.activated.connect(lambda: self.dir_pressed('up', 15))
        left_shortcut.activated.connect(lambda: self.dir_pressed('left', -15))
        down_shortcut.activated.connect(lambda: self.dir_pressed('down', -15))
        right_shortcut.activated.connect(lambda: self.dir_pressed('right', 15))

        shift_up_shortcut.activated.connect(lambda: self.dir_pressed('up', 1))
        shift_left_shortcut.activated.connect(lambda: self.dir_pressed('left', -1))
        shift_down_shortcut.activated.connect(lambda: self.dir_pressed('down', -1))
        shift_right_shortcut.activated.connect(lambda: self.dir_pressed('right', 1))

    def done(self, result):
        super().done(result)

    @qasync.asyncSlot()
    async def dir_pressed(self, dir, amount):
        if dir == 'up':
            await self.motor_conn.send_command_async("MOVE_ELV_BY", amount)
        elif dir == 'left':
            await self.motor_conn.send_command_async("MOVE_AZM_BY", amount)
        elif dir == 'down':
            await self.motor_conn.send_command_async("MOVE_ELV_BY", amount)
        elif dir == 'right':
            await self.motor_conn.send_command_async("MOVE_AZM_BY", amount)

class ViewParamsDialog(QtWidgets.QDialog):
    def __init__(self, parent, params, *args, **kwargs):
        super().__init__(parent, *args, **kwargs)
        uic.loadUi("./gui/view_params_dialog.ui", self)

        self.label.setText(pprint.pformat(params))


if __name__ == '__main__':
    app = QtWidgets.QApplication(sys.argv)

    loop = qasync.QEventLoop(app)
    asyncio.set_event_loop(loop)

    window = MyMainWindow()
    window.show()
    with loop:
        loop.run_forever()
    # sys.exit(app.exec())

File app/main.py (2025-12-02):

#!/usr/bin/python3
#------------------------------------------------------------------------------
# THIS FILE IS DEPRECATED AND LEFT HERE FOR LEGACY REASONS
# THE FILE IS NOT IN USE BY app.py AND IS ONLY HERE FOR REFERENCE
#
#'main.py'                                          Hearn WSU-ECE
#                                                   17apr23
# Open-Source Antenna Pattern Measurement System
# Performs the following project-specific functions:
#   1.input parameters from 'params.json' file (pre-loaded by user) 
#   2.menu algorithm
#   3.calls RadioFunctions    
#       a) FastScan - coherent AM quick scan
#       b) AMmeas   - coherent AM fixed measurement 
#       c) NSmeas   - Noise Subtraction measurement 
#       d) post-processing - pattern plotting options
#------------------------------------------------------------------------------
#------------------------------------------------------------------------------
# WSU-ECE legal statement here
#------------------------------------------------------------------------------
from PlotGraph import PlotGraph
import RadioFunctions
import traceback
#
def main():
    quit = False
    data = None    
    #--------------------------------------------------------------------------
    # user should preload measurement parameters in "params.json" file
    #--------------------------------------------------------------------------
    param_filename="params.json"
    menu_choices = []
    menu_choices.append("FastScan AUT w/ coherent AM method")              # 1
    menu_choices.append("Measure  AUT w/ coherent AM method")              # 2
    menu_choices.append("Measure  AUT w/ NoiseSub NS method")              # 3
    menu_choices.append("Plot last run data")                              # 4
    menu_choices.append("Plot data from file")                             # 5
    menu_choices.append("Plot data from two files")                        # 6
    menu_choices.append("Capture single measurement")                      # 7
    menu_choices.append("Capture single background")                       # 8
    menu_choices.append("Quit")                                            # 9
    menu_choices.append("FastScan AUT w/ coherent AM method and STM32")    # 10
    menu_choices.append("3D FastScan AUT w/ coeherent AM method repeated and STM32") # 11
    menu_choices.append("Connect to STM32 Motor")                          # 12
    #
    while not quit:
        try:
            selection = show_menu(menu_choices)               
            if selection == 1: 
                params = RadioFunctions.LoadParams(param_filename)
                data = RadioFunctions.do_AMscan(params)
                print(data)
            elif selection == 2: 
                params = RadioFunctions.LoadParams(param_filename)
                data = RadioFunctions.do_AMmeas(params)
                print(data)
            elif selection == 3: 
                params = RadioFunctions.LoadParams(param_filename)
                data = RadioFunctions.do_NSmeas(params)
                print(data)
            elif selection == 4:                              
                if data is None:                              
                    print("run scan before plotting data\n")  
                    continue                                  
                title = input("Enter a title for the graph: ")
                plot_graph = PlotGraph(data, title)           
                plot_graph.show()                             
            elif selection == 5:                               
                RadioFunctions.PlotFile()                     
            elif selection == 6:                              
                RadioFunctions.PlotFiles()                    
            elif selection == 7:                              
                print("Single measurement")                   
                data = RadioFunctions.do_single(Tx=True)      
                print("RMS = {:.3e}".format(data))            
            elif selection == 8:                              
                print("Single background measurement")        
                data = RadioFunctions.do_single(Tx=False)     
                print("RMS = {:.3e}".format(data))            
            elif selection == 9:                              
                print("Exiting...\n")                         
                quit = True                                   
            elif selection == 10:
                print("AM SCAN with STM32")
                params = RadioFunctions.LoadParams(param_filename)
                RadioFunctions.do_AMscan_STM32(params)
            elif selection == 11:
                print("3D SCAN with STM32")
                params = RadioFunctions.LoadParams(param_filename)
                RadioFunctions.do_3Dscan_STM32(params)
            elif selection == 12:
                params = RadioFunctions.LoadParams(param_filename)
                RadioFunctions.stm32_connect(params)
        except Exception as e:                                
            print("Operation failed")                         
            print(e)                                          
            print(traceback.format_exc())                     
            input("Press enter to continue")                  
    return                                                    # exit-user quit
#------------------------------------------------------------------------------
def show_menu(choices):                                       #
    if choices == []:                                         #
        return None                                           #
    row_num = 1                                               # print choices
    print("\n\n\n")                                           # on screen
    print("Please select from the following options:\n\n")    #
    for choice in choices:                                    #
        print(str(row_num)+": "+str(choice)+"\n")             #
        row_num += 1                                          #
    print("\n")                                               #
    selection = 0                                             # get response
    while selection < 1 or selection > len(choices):          #
        try:                                                  #
            selection = int(input("Please enter selection: "))#
        except ValueError:                                    #
            selection = 0                                     #
    return selection                                          #
#------------------------------------------------------------------------------
if __name__ == "__main__":                                    #
    main()                                                    # EoF

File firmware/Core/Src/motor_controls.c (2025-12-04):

/*
 * motor_controls.c
 *
 *  Created on: Apr 2, 2025
 *      Author: tydav
 */

#include "motor_controls.h"
#include "stm32l0xx_it.h"
#include "system_state.h"

extern UART_HandleTypeDef huart2;
extern TIM_HandleTypeDef htim21;
extern TIM_HandleTypeDef htim22;

void start_motor_movement(MotorState *motor_state) {
	if (motor_state->motor_count == 0) {
		return;
	}
	// set the direction pin
	if (motor_state->motor_direction == 1) {
		if (motor_state == &azm_motor_state) {
			HAL_GPIO_WritePin(AZM_DIR_PORT, AZM_DIR_PIN, GPIO_PIN_RESET);
		} else if (motor_state == &elv_motor_state) {
			HAL_GPIO_WritePin(ELV_DIR_PORT, ELV_DIR_PIN, GPIO_PIN_RESET);
		}
	} else {
		if (motor_state == &azm_motor_state) {
			HAL_GPIO_WritePin(AZM_DIR_PORT, AZM_DIR_PIN, GPIO_PIN_SET);
		} else if (motor_state == &elv_motor_state) {
			HAL_GPIO_WritePin(ELV_DIR_PORT, ELV_DIR_PIN, GPIO_PIN_SET);
		}
	}

	// start the timer
	if (motor_state == &azm_motor_state) {
		HAL_TIM_Base_Start_IT(&htim21);
	} else if (motor_state == &elv_motor_state) {
		HAL_TIM_Base_Start_IT(&htim22);
	}
}

void dance() {

}

void set_motor_enable(MotorState *motor_state, uint8_t set) {
	motor_state->motor_enable = set;
	if (set) {
		if (motor_state == &azm_motor_state) {
			HAL_GPIO_WritePin(AZM_EN_PORT, AZM_EN_PIN, GPIO_PIN_SET);
		} else if (motor_state == &elv_motor_state) {
			HAL_GPIO_WritePin(ELV_EN_PORT, ELV_EN_PIN, GPIO_PIN_SET);
		}
	} else {
		if (motor_state == &azm_motor_state) {
			HAL_GPIO_WritePin(AZM_EN_PORT, AZM_EN_PIN, GPIO_PIN_RESET);
		} else if (motor_state == &elv_motor_state) {
			HAL_GPIO_WritePin(ELV_EN_PORT, ELV_EN_PIN, GPIO_PIN_RESET);
		}
	}
}

uint8_t move_motor_by(int32_t degrees, MotorState *motor_state) {
	int32_t l_degrees = degrees;
	if (l_degrees < 0) {
		l_degrees *= -1;
		motor_state->motor_direction = 1;
	} else {
		motor_state->motor_direction = 0;
	}

	uint64_t count_calc = l_degrees * motor_state->tooth_ratio;
	count_calc /= 360;
	count_calc *= motor_state->motor_pulse_rev;
	count_calc /= 100000;
	motor_state->motor_count = (uint32_t)count_calc;

	start_motor_movement(motor_state);
	return 0;
}

uint8_t move_motor_to(int32_t degrees, MotorState *motor_state) {
	// find the target motor_state->motor_position
	int64_t count_calc = degrees;
	count_calc *= motor_state->tooth_ratio;
	count_calc /= 360;
	count_calc *= 6400;
	count_calc /= 100000;
	// count_calc now stores the target motor_state->motor_position

	// get the difference between where it needs to be and where it is
	count_calc = count_calc - motor_state->motor_position;
	count_calc *= motor_state->motor_pulse_rev;
	count_calc /= 6400;
	// count_calc now knows how many steps to get to its destination

	if (count_calc < 0) {
		count_calc *= -1;
		motor_state->motor_direction = 1;
	} else {
		motor_state->motor_direction = 0;
	}
	motor_state->motor_count = (uint32_t)count_calc;
	start_motor_movement(motor_state);
	return 0;
}

void HAL_TIM_PeriodElapsedCallback(TIM_HandleTypeDef *htim) {
	// AZIMUTH TIMER
	if (htim == &htim21) {
		HAL_GPIO_TogglePin(AZM_PUL_PORT, AZM_PUL_PIN);

		// only update counts if it is set high
		if (HAL_GPIO_ReadPin(AZM_PUL_PORT, AZM_PUL_PIN)) {
			// update the position
			if (azm_motor_state.motor_direction == 0) {
				azm_motor_state.motor_position += 6400 / azm_motor_state.motor_pulse_rev;
			} else {
				azm_motor_state.motor_position -= 6400 / azm_motor_state.motor_pulse_rev;
			}
			if (azm_motor_state.motor_position > azm_motor_state.tooth_ratio * 6400 / 1000) {
				azm_motor_state.motor_position -= azm_motor_state.tooth_ratio * 6400 / 1000;
			}
			if (azm_motor_state.motor_position < -1 * azm_motor_state.tooth_ratio * 6400 / 1000) {
				azm_motor_state.motor_position += azm_motor_state.tooth_ratio * 6400 / 1000;
			}

			azm_motor_state.motor_count--;
			// stop if it has reached the number of iterations.
			if (azm_motor_state.motor_count == 0) {
				HAL_TIM_Base_Stop_IT(&htim21);
			}
		}
	}

	// ELEVATION TIMER
	if (htim == &htim22) {
		HAL_GPIO_TogglePin(ELV_PUL_PORT, ELV_PUL_PIN);

		if (HAL_GPIO_ReadPin(ELV_PUL_PORT, ELV_PUL_PIN)) {
			// update the position
			if (elv_motor_state.motor_direction == 0) {
				elv_motor_state.motor_position += 6400 / elv_motor_state.motor_pulse_rev;
			} else {
				elv_motor_state.motor_position -= 6400 / elv_motor_state.motor_pulse_rev;
			}
			if (elv_motor_state.motor_position > elv_motor_state.tooth_ratio * 6400 / 1000) {
				elv_motor_state.motor_position -= elv_motor_state.tooth_ratio * 6400 / 1000;
			}
			if (elv_motor_state.motor_position < -1 * elv_motor_state.tooth_ratio * 6400 / 1000) {
				elv_motor_state.motor_position += elv_motor_state.tooth_ratio * 6400 / 1000;
			}

			elv_motor_state.motor_count--;
			// stop if it has reach the number of iterations
			if (elv_motor_state.motor_count == 0) {
				HAL_TIM_Base_Stop_IT(&htim22);
			}
		}
	}
}

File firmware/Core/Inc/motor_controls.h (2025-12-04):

/*
 * motor_controls.h
 *
 *  Created on: Apr 2, 2025
 *      Author: tydav
 */

#ifndef INC_MOTOR_CONTROLS_H_
#define INC_MOTOR_CONTROLS_H_

#include "stm32l0xx_hal.h"
#include "system_state.h"

// azimuth motor
#define AZM_PUL_PORT  GPIOA
#define AZM_PUL_PIN   GPIO_PIN_8

#define AZM_DIR_PORT  GPIOB
#define AZM_DIR_PIN   GPIO_PIN_10

#define AZM_EN_PORT   GPIOB
#define AZM_EN_PIN    GPIO_PIN_4

// elevation motor
#define ELV_PUL_PORT  GPIOB
#define ELV_PUL_PIN   GPIO_PIN_5

#define ELV_DIR_PORT  GPIOB
#define ELV_DIR_PIN   GPIO_PIN_3

#define ELV_EN_PORT   GPIOA
#define ELV_EN_PIN    GPIO_PIN_10

uint8_t move_motor_by(int32_t, MotorState*);
uint8_t move_motor_to(int32_t, MotorState*);
void set_motor_enable(MotorState*, uint8_t);
void dance();



#endif /* INC_MOTOR_CONTROLS_H_ */

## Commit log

2025-11-04 Ready to test with motors and incorporation with existing structure
2025-11-06 Prototype for 3d scan code
2025-11-09 Added all the csvs
    [04-Nov-2025_08-21-57_antenna_data.csv, 04-Nov-2025_08-22-03_antenna_data.csv, 04-Nov-2025_08-25-04_antenna_data.csv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]
2025-11-10 Tried my best to analyze the 3d plotting. Will check in with Dr. Hearn tomorrow
    [04-Nov-2025_08-03-52_antenna_data.csv, 04-Nov-2025_08-05-11_antenna_data.csv, 04-Nov-2025_08-11-55_antenna_data.csv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]
2025-11-13 Working on 3d plotting still
    [11-Nov-2025_14-27-56_10_elvs.csv, 11-Nov-2025_14-30-06_10_elvs.csv, 11-Nov-2025_14-33-27_10_elvs.csv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]
2025-11-18 Working on 3d plotting with some simulation stuff
    [output.csv]
2025-11-19 Got the 3d plotting working correctly in the 3d plotting file. Still need to inspect what's going on with the elv not always rotating
    [18-Nov-2025_16-23-56.csv, 18-Nov-2025_16-24-31.csv, 18-Nov-2025_16-35-15.csv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]
2025-11-20 added some buttons
2025-11-20 Lots of progress on the scans
    [19-Nov-2025_17-47-38.csv, 19-Nov-2025_17-48-23_antenna_data.csv, 19-Nov-2025_17-49-15_antenna_data.csv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]
2025-11-20 Fixed some of the commands to support bigger number
    [20-Nov-2025_08-27-41_demo.csv, 20-Nov-2025_08-46-40_demo.csv, out.csv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]
2025-11-20 Going to make all of the send_command calls async
    [20-Nov-2025_10-43-53_demo.csv, 20-Nov-2025_10-47-40_demo.csv]
2025-12-02 Moved some data files to the data directory
    [04-Nov-2025_08-03-52_antenna_data.csv, 04-Nov-2025_08-05-11_antenna_data.csv, 04-Nov-2025_08-11-55_antenna_data.csv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]
2025-12-02 Removed a bunch of unnecessary files and moved project into app folder
    [04-Nov-2025_08-03-52_antenna_data.csv, 04-Nov-2025_08-05-11_antenna_data.csv, 04-Nov-2025_08-11-55_antenna_data.csv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]
2025-12-02 Got rid of legacy code.
    [output.csv]
2025-12-02 Added solidworks files
    [60pitch pulley GT2 6mm ASSEMBLY.STEP, 6455K147_Plastic Ball Bearing.SLDPRT, 6455K54_Plastic Ball Bearing.SLDPRT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]
2025-12-02 WIP: Working on async issues again
    [app.py, commands.py]
2025-12-03 Working on getting the async stuff to work by fixing how it connects to the STM32
    [app.py]
2025-12-04 Removed the scripts directory from here because it is now in the app directory instead
    [response.csv, status.csv]
2025-12-04 Fixing some little UI things
    [app.py]
2025-12-04 Consider locked motor state in the GUI, and you can move both motors at once now
2025-12-04 Fixed motor directions move to 0 bug
    [motor_controls.c]
2025-12-04 Fixed the 360 degree rollover bug and the 16-bit transmission of position bug
    [app.py, codes.py, command_parser.c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]
2025-12-04 Updating the phi-cut scan
